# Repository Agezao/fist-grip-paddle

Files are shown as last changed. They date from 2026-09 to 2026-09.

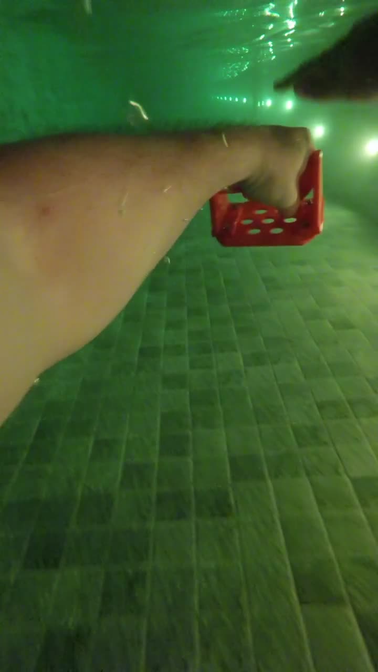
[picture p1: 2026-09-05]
img/test-run-poster.jpg

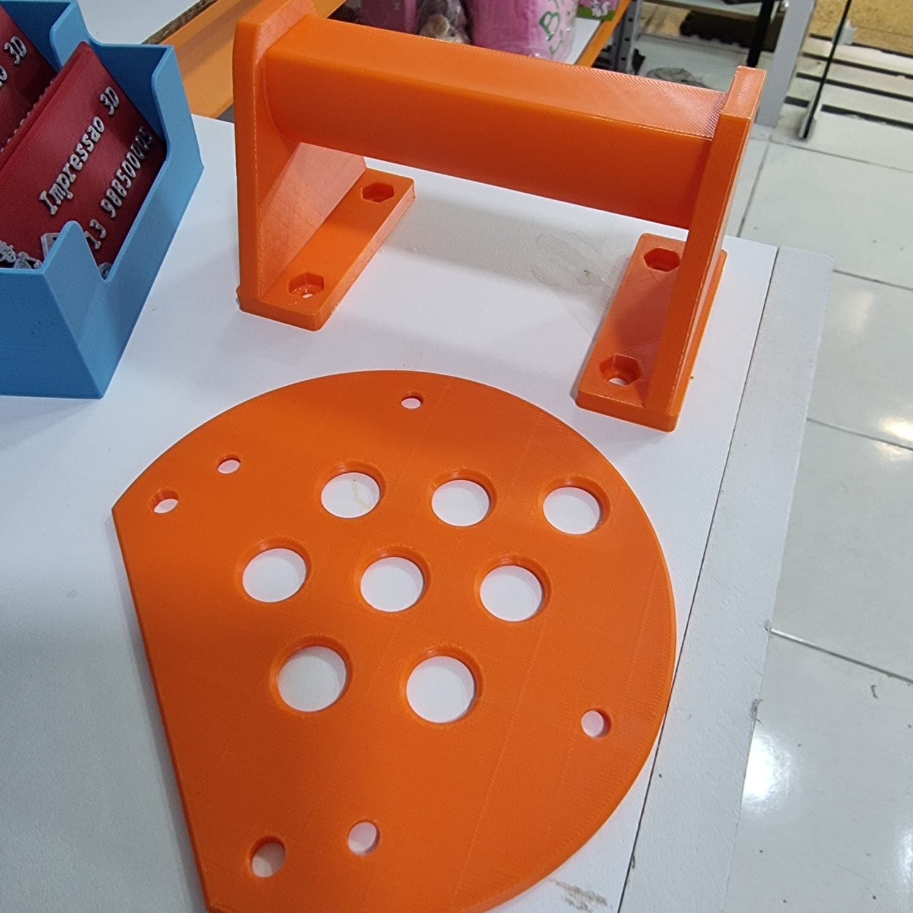
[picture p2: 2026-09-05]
img/printed_fist_paddle.jpg

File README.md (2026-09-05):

# Fist-Grip Swim Paddle -- [see the project here](https://agezao.github.io/fist-grip-paddle/)

A 3D-printable swim paddle held by a bar inside a closed fist, instead of strapped flat to an open palm.

It was designed for swimmers with hemiplegia. Spasticity holds the affected hand closed, and a closed fist presents almost no surface to the water — which is why "fist gloves" are sold to able-bodied swimmers as a drill to *remove* feel. An ordinary hand paddle assumes an open palm and a working grip, so it is not an option. This paddle gives the closed fist back roughly the pushing surface an open hand would have had, without requiring the hand to open or to grip.

Everything is parametric. The point of this repository is not the STLs — it is the `.scad` file, so you can fit it to a specific person.

---

## Safety first

This is an unregulated, home-made device used in water. Read this part.

- **Get a physiotherapist or occupational therapist involved.** Not as a formality. They can position the arm to measure the wrist angle the design depends on, and they can judge whether adding drag to the affected arm is safe. Shoulder subluxation is common on the hemiplegic side.
- **Check the skin after every one of the first several sessions**, especially where the palm sits on the bar's flat and where the fingertips press against the plate. Reduced sensation on the affected side is normal, which means a pressure mark can develop without being felt.
- **Never use a closed loop the hand cannot be pulled out of.** If you fit a wrist tether, use elastic shock cord so it stretches off under load. Webbing that cinches is the wrong choice here.
- **Supervised water only**, at least until the swimmer and whoever helps them are confident in donning and removing it quickly.
- This is not a flotation aid and does nothing to keep anyone afloat.
- Start with short sets. Paddles are a well-known route into shoulder trouble even for unimpaired swimmers.

---

## How it works

The non-obvious part is which side of the fist the plate goes on, and it follows from tracing the load.

The plate sits on the palm side, past the fingertips. During the pull, water pushes the plate *toward* the hand. That force travels up the struts into the bar, and the bar presses into the palm. The arm resists it directly.

**No grip strength is used for propulsion.** The fingers only matter during the recovery, when the arm is out of the water and forces are small — and spastic flexor tone tends to close the fingers around the bar on its own, which for once works in our favour.

If you flipped it and put the plate on the back-of-hand side, every newton of propulsion would try to rip the paddle out of the hand and grip strength would be the only thing holding it. That version does not work for anyone, and especially not here.

The design is symmetric, so the same files serve a left or a right hand.

---

## What you print

| Part | File | Time | Notes |
|---|---|---|---|
| Fit gauge | `grip_fit_gauge.stl` | ~1 h | A 44 mm slice of the grip. **Print this first.** |
| Grip module | `grip_module.stl` | ~3 h | The fitted part. Supports needed under the bar. |
| Plate | `plate_120mm.stl` … `plate_165mm.stl` | ~1.5 h | Bolts on, swappable. Start small. |

Plus **4 × M5 × 16 A4 stainless countersunk bolts and M5 A4 nyloc nuts**. Bolt heads sit flush on the water face; nuts drop into hex pockets, so it assembles with a screwdriver alone. File flush any thread poking above a nut.

### Print settings

- **PETG or ABS.** Not PLA — it softens in a warm pool and creeps under sustained load.
- Grip module: flanges down on the bed, **supports under the bar only**. Slicers like to fill the hex nut pockets with support too; paint supports manually or raise the overhang threshold.
- Plate: flat on the bed, no supports.
- 4 perimeters minimum. The struts carry everything.
- 25 % infill is plenty. Grip module ≈ 74 g, plates 22–41 g.

---

## Fitting it — the actual workflow

**1. Print the fit gauge.** It has the real bar, real span, real palm flat, real standoff, at a fraction of the print time.

**2. Try it on a table.** Set it flat, open the fist with the other hand, lower it on. You are checking three things:

- the fist fits the span, with the thumb wherever it naturally falls
- the palm settles onto the flat rather than rolling off it
- the fingertips clear the plate strip with a little room

Adjust, reprint the gauge, repeat. This loop costs an hour.

**3. Find the wrist angle.** This is the parameter most likely to need a second attempt and the one you cannot judge from a table top. Have the therapist hold the arm in the catch position with the gauge on the hand, and look at where the plate faces. It should be roughly square to the direction of the pull. A spastic wrist usually sits flexed and pronated, so the answer is rarely zero. Photograph it from the side and measure off the photo if that helps.

**4. Print the grip module** with `grip_angle` set, and one plate.

**5. Swim, then increase plate size** only if the stroke rate holds and the shoulder stays quiet.

---

## Parameter reference

Open `fist_paddle.scad`. Everything above the `[Hidden]` marker is meant to be edited. Press **F5** to preview, **F6** for the real render, then **File → Export → Export as STL**. Always F6 before exporting or you can get a broken mesh.

Set `part` to `gripcheck`, `grip`, `plate`, or `full` to choose what gets built.

### The ones that decide fit

| Parameter | What it is | How to find your number |
|---|---|---|
| `clear_span` | Clear width between the struts | Widest point across the closed fist, including the thumb where it lies, plus 8–10 mm |
| `grip_z` / `grip_y` | Bar oval, toward the plate / fore-aft | The natural aperture inside the resting fist. Too large and the hand will not go on |
| `palm_flat` | Width of the flat the palm seats on | 20 mm suits most hands. Larger keys the angle harder; 0 removes it |
| `standoff` | Plate face to bar axis | Bar axis to the outermost point of the curled fingers, plus 8–12 mm |
| `grip_angle` | Hand tilt relative to the plate | Measured on the swimmer in the catch position. Positive raises the wrist end |

### The ones that decide how it swims

| Parameter | Effect |
|---|---|
| `plate_dia` | Pushing area. Below 135 mm the strut feet overhang the rim — usable, just file the corners |
| `hole_dia`, `hole_pitch` | More or bigger holes soften the catch and reduce load |
| `plate_thk` | Stiffness and mass. The arm lifts this clear of the water every stroke |
| `wrist_trim_f` | How much of the wrist edge is cut away, as a fraction of diameter |

### Do not hand-tune the disc offset

`plate_shift` is solved, not set. Trimming the wrist edge pulls the plate's area centroid toward the fingertips, and at the angles a paddle actually works at, the centre of pressure sits near that centroid. If it does not line up with the bar axis, water spends the whole stroke twisting the paddle in the hand — a nuisance for any swimmer and unmanageable without grip. The file bisects for the offset that puts the centroid on the axis, and re-solves whenever you change a dimension. Change `plate_dia` or `wrist_trim_f` freely; the balance follows.

---

## Comfort and pressure

Sleeve the bar in silicone tube or adhesive neoprene. It spreads pressure over skin that may not report a problem, and it stops printed layer lines abrading. **If you do, subtract twice the sleeve thickness from `grip_z` and `grip_y` before printing.**

Thread a bungee wrist loop through the two holes at the wrist edge of the plate. Elastic, not webbing. It is a backup for the recovery phase, not part of the load path.

---

## Troubleshooting

| Symptom | Try |
|---|---|
| Paddle twists in the hand during the pull | Increase `palm_flat`; check `grip_angle` is right |
| Hand will not go onto the bar | Reduce `grip_z` / `grip_y`; increase `clear_span` |
| Fingertips sore or marked | Increase `standoff` |
| Plate contacts the forearm at the catch | Increase `wrist_trim_f` |
| Pushes water at the wrong angle | Adjust `grip_angle` and reprint the grip module |
| Too much load on the shoulder | Smaller plate, or larger `hole_dia` |
| Red marks across the palm | Sleeve the bar; reduce `palm_flat` |
| Hand slides side to side | Reduce `clear_span` |

---

## Contributing

The most useful contributions are fitting reports: hand dimensions, the parameter values that worked, and what you had to change. That is the data this design lacks. Photographs of the device in use, with consent, help more than renders.

If you are a clinician and something here is wrong, please open an issue. This was engineered from first principles, not from clinical practice, and it has been tested by very few people.

## License

<!-- Suggested: CERN-OHL-S or CC BY-SA 4.0 for hardware. Pick one and replace this line. -->

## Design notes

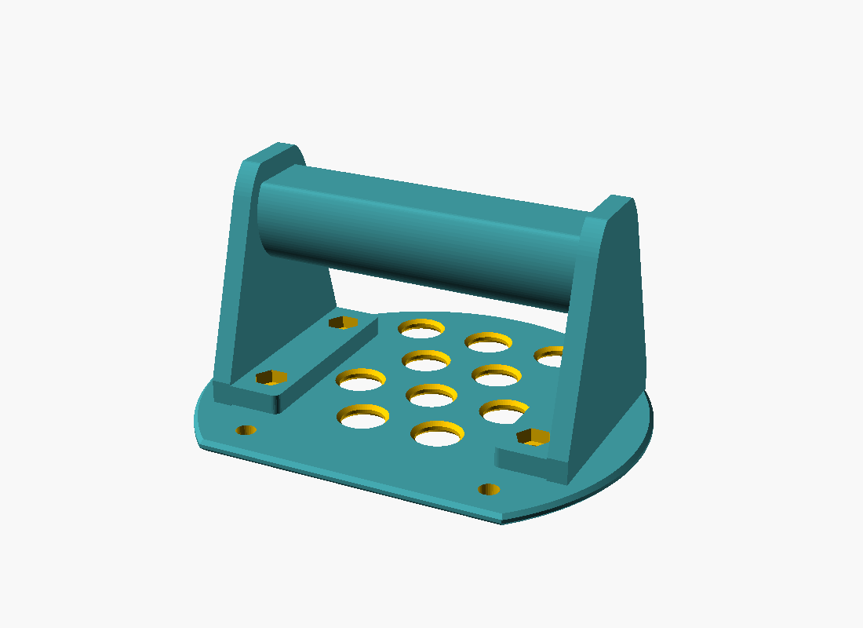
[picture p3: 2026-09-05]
img/3d_view.png

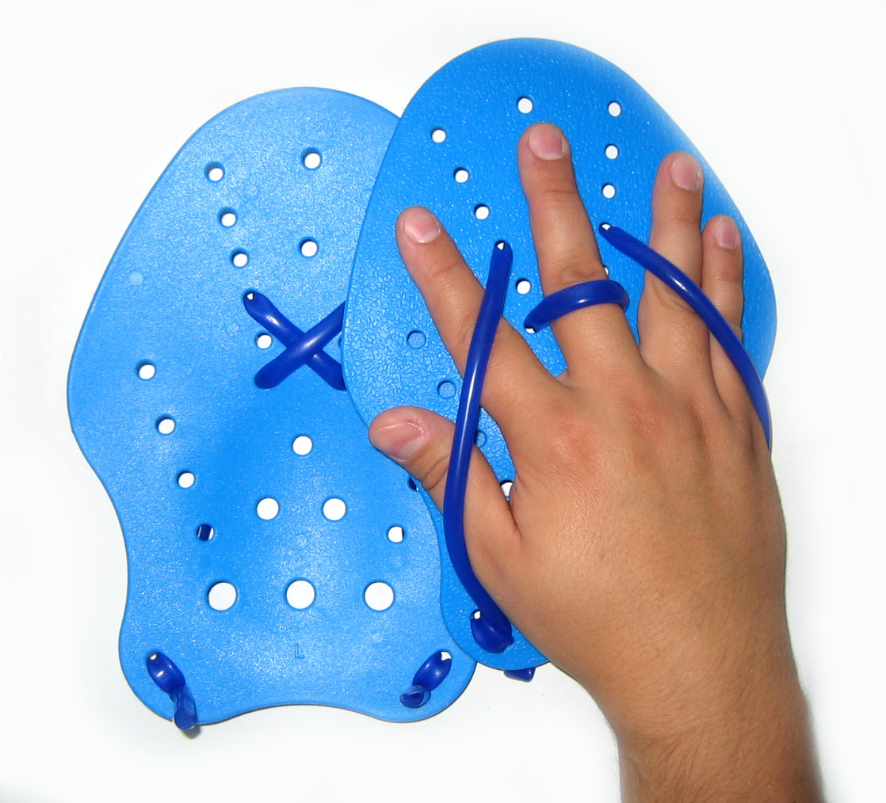
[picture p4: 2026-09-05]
img/regular_paddle.jpeg

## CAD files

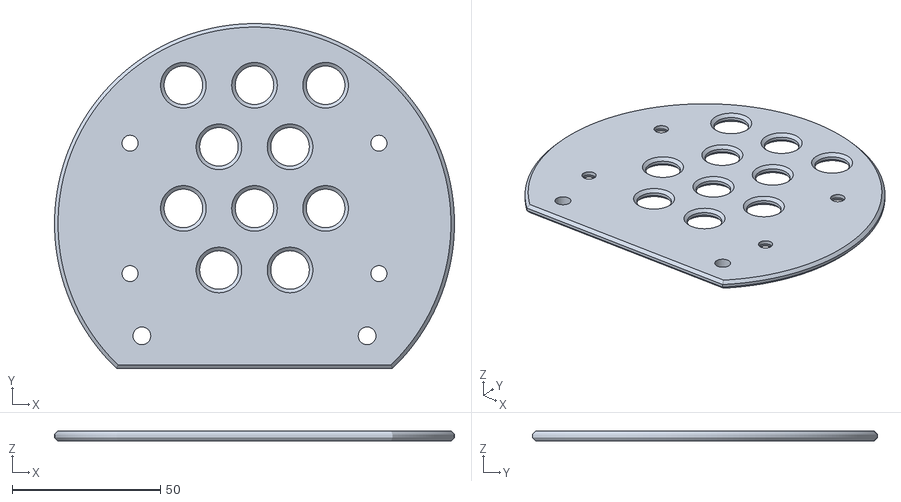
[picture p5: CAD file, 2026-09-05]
plate_135mm.stl
135.0 x 116.4 x 3.50

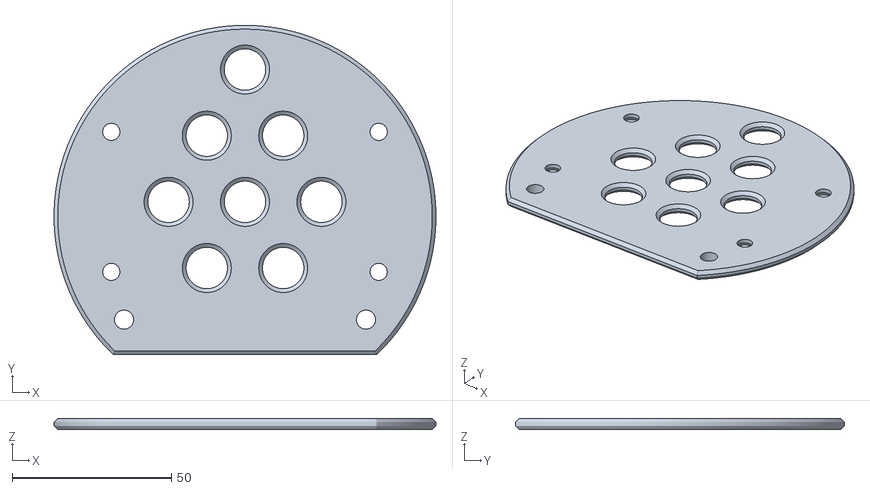
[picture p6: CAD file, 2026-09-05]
plate_120mm.stl
120.0 x 103.4 x 3.50

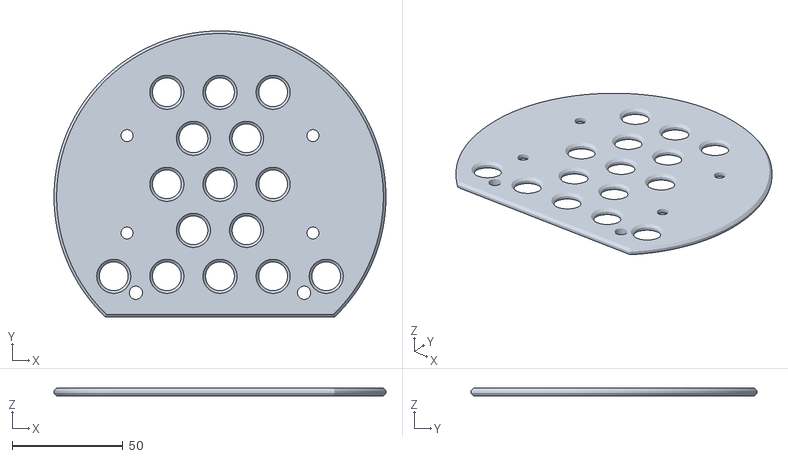
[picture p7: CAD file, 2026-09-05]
plate_150mm.stl
150.0 x 129.3 x 3.50

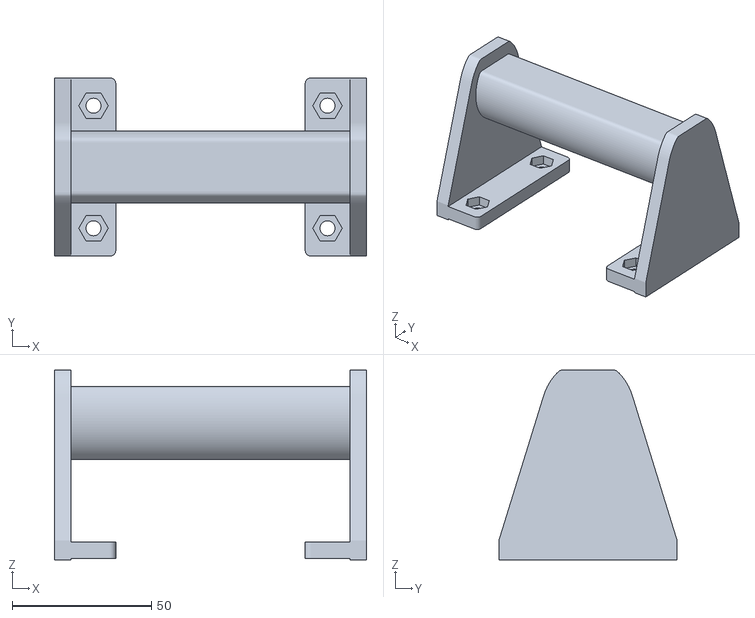
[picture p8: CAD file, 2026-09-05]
grip_module.stl
112.0 x 64.0 x 68.2

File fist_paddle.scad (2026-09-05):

// Fist-grip swim paddle - v2, modular
//
// An adaptive paddle for a hemiplegic swimmer whose hand rests closed.
// The fist is laid onto a bar rather than gripping one, so propulsion needs
// no grip strength: water pushes the plate toward the hand, the bar bears on
// the palm, and the load goes into the arm through the fist, not the fingers.
//
// Two printed parts bolted together:
//   "grip"  - the bar, struts and mounting flanges. Fitted once to the hand.
//   "plate" - the pushing surface. Print several diameters and swap them.
// Joined by 4 x M5 A4 stainless countersunk bolts, heads flush on the water
// face, nyloc nuts in hex pockets on top.
//
// Axes:  X = along the grip bar
//        Y = +distal (fingertips) / -proximal (wrist)
//        Z = 0 is the water face; +Z toward the hand
// The XY origin sits under the grip bar axis.
//
// Donning, one-handed: set the paddle plate-down on the deck, open the fist
// with the good hand, lower it onto the bar. Flexor tone closes the fingers.
// The tether is a backup for the recovery, not part of the load path.

/* [What to build] */
// full      - both parts assembled, for looking at
// plate     - the pushing surface, printable
// grip      - the bar and struts, printable
// gripcheck - a 44 mm slice of the grip. Under an hour to print, and it tells
//             you whether the span, the oval and the standoff suit the hand.
part          = "full";  // [full, plate, grip, gripcheck]

/* [Paddle plate] */
plate_dia     = 135;   // minimum is set by clear_span, see the check below
plate_thk     = 3.5;
wrist_trim_f  = 0.40;  // wrist edge trim, as a fraction of plate_dia
edge_round    = 1.2;
tether_holes  = true;  // anchors for a bungee wrist loop

/* [Grip] */
standoff      = 45;    // plate top face to the bar axis
grip_z        = 32;    // bar oval, measured toward the plate
grip_y        = 26;    // bar oval, measured fore-aft
palm_flat     = 20;    // width of the flat the palm seats on. 0 for none.
clear_span    = 100;   // clear width for the fist - MEASURE THIS ONE
grip_angle    = 0;     // degrees. Positive pitches the fingertip edge of the
                       // plate down relative to the hand. A spastic wrist
                       // usually sits flexed, so this will not stay at zero.

// If you sleeve the bar in silicone or neoprene for pressure relief, subtract
// twice the sleeve thickness from grip_z and grip_y before printing.

/* [Struts] */
strut_thk     = 6;
strut_wall    = 4;     // material wrapped around the bar ends
strut_foot    = 64;    // fore-aft length of the mounting flange
flange_w      = 20;
flange_thk    = 7;

/* [Perforation] */
hole_dia      = 13;
hole_pitch    = 24;
hole_margin   = 7;

/* [Fasteners] */
bolt_d        = 5.4;   // M5 clearance
bolt_head_d   = 9.6;   // countersunk head
nut_af        = 9.2;   // M5 nyloc across flats
nut_deep      = 4.5;
bolt_x        = 42;
bolt_y        = 22;

/* [Hidden] */
$fa = 2;
$fs = 0.5;
plate_r    = plate_dia / 2;
wrist_trim = plate_dia * wrist_trim_f;
strut_x    = clear_span / 2 + strut_thk / 2;
flange_x   = strut_x - 9;
bar_z      = flange_thk + standoff;
bar_len    = clear_span + 2 * strut_thk;
eps        = 0.01;

// ---------------------------------------------------------------- balance
// Trimming the wrist edge pulls the plate's area centroid toward the
// fingertips. At the high angles of attack a paddle works at, the centre of
// pressure sits near that centroid, so if it does not line up with the bar
// axis the water spends the whole stroke twisting the paddle in the hand.
// That is a problem for any swimmer and an unmanageable one without grip.
// These functions slide the disc back until the centroid lands on the axis,
// and they re-solve whenever a dimension above changes.

function _th(s)   = 2 * acos((s + wrist_trim) / plate_r);
function _thr(s)  = _th(s) * PI / 180;
function _capA(s) = plate_r * plate_r * (_thr(s) - sin(_th(s))) / 2;
function _capC(s) = s - (4 * plate_r * pow(sin(_th(s) / 2), 3))
                        / (3 * (_thr(s) - sin(_th(s))));
function _cent(s) = (PI * plate_r * plate_r * s - _capA(s) * _capC(s))
                    / (PI * plate_r * plate_r - _capA(s));
function _solve(lo, hi, n) =
    n <= 0 ? (lo + hi) / 2
           : let (m = (lo + hi) / 2)
             _cent(m) > 0 ? _solve(lo, m, n - 1) : _solve(m, hi, n - 1);

plate_shift = wrist_trim >= plate_r
    ? 0
    : _solve(-wrist_trim + 1, plate_r - wrist_trim, 44);

bolt_reach  = sqrt(pow(bolt_x, 2) + pow(bolt_y - plate_shift, 2));
foot_reach  = sqrt(pow(flange_x + flange_w / 2, 2)
                   + pow(strut_foot / 2 - plate_shift, 2));

echo(str("plate ", plate_dia, " mm, disc offset ", plate_shift, " mm"));
echo(str("bolt circle reaches ", bolt_reach, " of ", plate_r, " mm available"));
echo(str("strut feet reach ", foot_reach, " mm"));
if (bolt_reach > plate_r - 9)
    echo("WARNING: plate too small for the bolt pattern, raise plate_dia");
if (foot_reach > plate_r)
    echo("WARNING: strut feet overhang the plate rim, raise plate_dia");

// ---------------------------------------------------------------- plate

module plate_outline() {
    intersection() {
        translate([0, plate_shift]) circle(r = plate_r, $fn = 220);
        translate([-plate_dia, -wrist_trim]) square([2 * plate_dia, 2 * plate_dia]);
    }
}

module plate_blank() {
    hull() {
        linear_extrude(eps) offset(r = -edge_round) plate_outline();
        translate([0, 0, edge_round])
            linear_extrude(plate_thk - 2 * edge_round) plate_outline();
        translate([0, 0, plate_thk - eps])
            linear_extrude(eps) offset(r = -edge_round) plate_outline();
    }
}

function hole_fits(px, py) =
    (sqrt(pow(px, 2) + pow(py - plate_shift, 2)) <= plate_r - hole_dia / 2 - hole_margin)
    && (py >= -wrist_trim + hole_dia / 2 + hole_margin)
    && !(abs(px) + hole_dia / 2 + 3 > flange_x - flange_w / 2
         && abs(px) - hole_dia / 2 - 3 < flange_x + flange_w / 2
         && abs(py) < strut_foot / 2 + hole_dia / 2 + 3);

module hole_cut() {
    cylinder(d = hole_dia, h = plate_thk + 4, center = true, $fn = 60);
    translate([0, 0, plate_thk / 2 - 1.2])
        cylinder(d1 = hole_dia, d2 = hole_dia + 2.4, h = 1.2, $fn = 60);
    translate([0, 0, -plate_thk / 2])
        cylinder(d1 = hole_dia + 2.4, d2 = hole_dia, h = 1.2, $fn = 60);
}

module perforation() {
    rows = ceil((plate_dia + wrist_trim) / (hole_pitch * 0.866)) + 1;
    cols = ceil(plate_dia / hole_pitch) + 1;
    for (j = [-rows : rows], i = [-cols : cols]) {
        px = i * hole_pitch + (j % 2 == 0 ? 0 : hole_pitch / 2);
        py = j * hole_pitch * 0.866;
        if (hole_fits(px, py))
            translate([px, py, plate_thk / 2]) hole_cut();
    }
}

module countersunk_bolt() {
    translate([0, 0, -1]) cylinder(d = bolt_d, h = plate_thk + 2, $fn = 40);
    translate([0, 0, -eps])
        cylinder(d1 = bolt_head_d, d2 = bolt_d, h = (bolt_head_d - bolt_d) / 2, $fn = 40);
}

module plate_part() {
    difference() {
        plate_blank();
        perforation();
        for (sx = [-1, 1], sy = [-1, 1])
            translate([sx * bolt_x, sy * bolt_y, 0]) countersunk_bolt();
        if (tether_holes)
            for (sx = [-1, 1])
                translate([sx * 38, -wrist_trim + 11, -1])
                    cylinder(d = 6, h = plate_thk + 2, $fn = 30);
    }
}

// ---------------------------------------------------------------- grip
// Profile is drawn in local XY, which maps to global (Z, Y). Rotating the
// bar placement about the local origin tilts the hand relative to the plate
// while leaving the mounting flange flat, so the bolts stay perpendicular.

// The oval alone is a weak angular key. A flat on the side the palm rests
// against gives the hand a definite seat, which matters a great deal when
// there is no voluntary grip to resist the water twisting the paddle.
// Corners are opened out so no edge presses into skin that cannot feel it.

function flat_x(a, b) = palm_flat <= 0 || palm_flat / 2 >= b
    ? a * 2
    : a * sqrt(1 - pow(palm_flat / 2 / b, 2));

module bar_section_2d(grow = 0) {
    a = grip_z / 2 + grow;
    b = grip_y / 2 + grow;
    translate([bar_z, 0])
        rotate(grip_angle)
            offset(r = 2) offset(r = -2)
                intersection() {
                    resize([2 * a, 2 * b]) circle(d = grip_z, $fn = 96);
                    translate([flat_x(a, b) - 100, 0])
                        square([200, 200], center = true);
                }
}

module strut_profile() {
    hull() {
        bar_section_2d(strut_wall);
        translate([flange_thk / 2, 0]) square([flange_thk, strut_foot], center = true);
    }
}

module strut(xp) {
    translate([xp, 0, 0])
        rotate([0, -90, 0])
            linear_extrude(height = strut_thk, center = true) strut_profile();
}
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

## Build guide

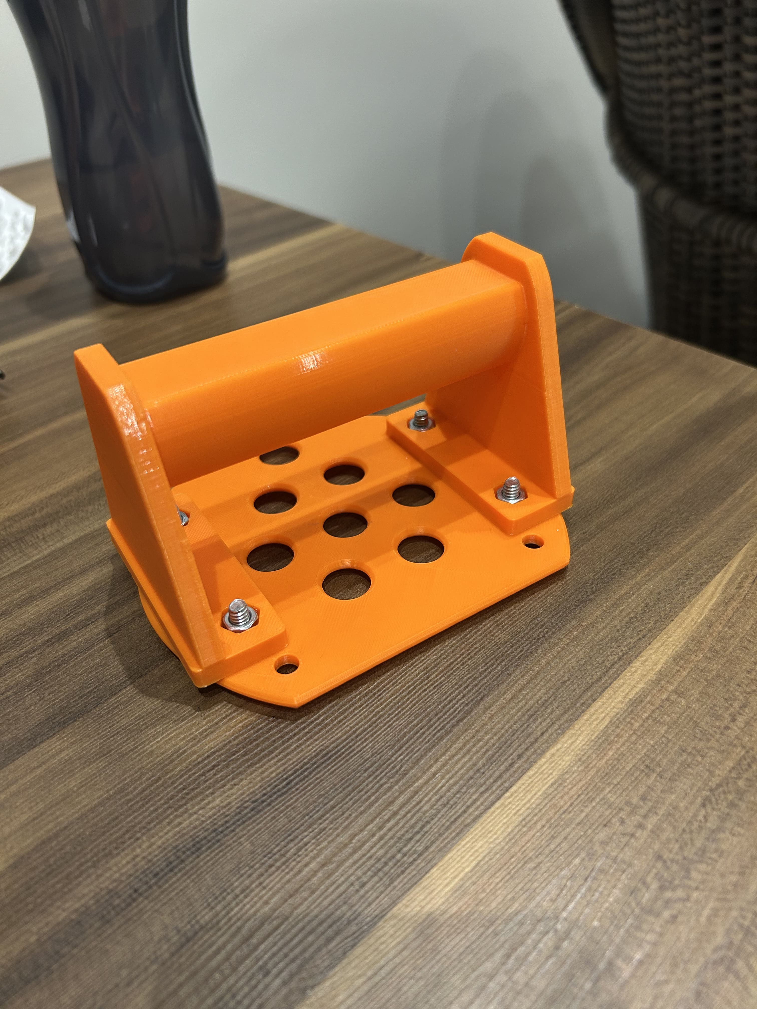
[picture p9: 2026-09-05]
img/assembled_fist_paddle.jpg
